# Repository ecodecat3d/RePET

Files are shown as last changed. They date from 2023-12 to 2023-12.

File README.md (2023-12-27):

# RePET

RePET is a groundbreaking system designed for 3D printing using plastic bottles as raw material. The key to this system lies in the combination of various components that collaborate in transforming plastic bottles into filament suitable for 3D printing. Firstly, a heating block capable of reaching 230 degrees Celsius is complemented by a 1.6mm nozzle, playing an essential role in allowing controlled filament output.

The process begins with the preparation of plastic bottles, which are cut into strips using a specialized bottle cutter. These strips are then joined to form a larger coil, ensuring a continuous supply during printing and avoiding interruptions each time a bottle strip is depleted. During the printing process, the coil passes through the heating block, where the application of heat causes the deformation of the strips, generating the required 1.75mm filament.

The final stage of the process involves the entry of the deformed filament into the 3D printer's extruder. At this point, the printer's motor takes on the responsibility of generating the necessary force to extrude the filament in a controlled manner. This approach not only stands out for its technical innovation but also promotes sustainability by reusing materials, contributing to the reduction of plastic waste, and providing a creative and eco-friendly solution for 3D printing manufacturing.

### Atention!
This system has been implemented for Mingda printers. You can use the discount code 'ecodecat3d' for a €50 discount on your printers (Link to their website: https://3dmingdaofficial.com/es/collections/magician-series/products/magician-x2). If you wish to implement the system on your printer, you will need to edit the provided STEP files for your printer. Prior to implementation, ensure that the extruder can generate a minimum torque of 5kg*cm (equivalent to a Nema17 motor), operates at 24V, and is capable of printing at 255 degrees.



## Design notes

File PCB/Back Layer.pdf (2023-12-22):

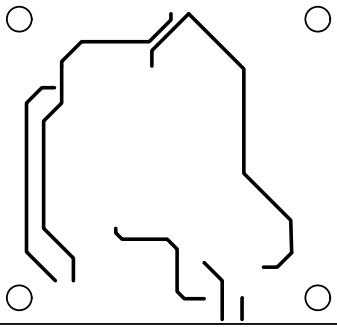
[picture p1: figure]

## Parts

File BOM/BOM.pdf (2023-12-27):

EXTRUDER
COMPONENT | LINK | UNITS
Reductor 24V - 5V | ALIEXPRESS (https://s.click.aliexpress.com/e/_DCE2X0N) | 1
Wemos D1 Mini | ALIEXPRESS (https://s.click.aliexpress.com/e/_DBl6T5X) | 1
10K, 1K resistances | ALIEXPRESS (https://s.click.aliexpress.com/e/_DdqEEZT) | 1
Push Button NO | ALIEXPRESS (https://s.click.aliexpress.com/e/_Dedzl33) | 1
2 pin 2,54mm Male | ALIEXPRESS (https://s.click.aliexpress.com/e/_DkpdfzR) | 1
Heat Shrink | ALIEXPRESS (https://s.click.aliexpress.com/e/_DdkWyCv) | 1
16 AWG Cable | ALIEXPRESS (https://s.click.aliexpress.com/e/_DEuP3uV) | 1
2,4 pin Connector with Cable JST ALIEXPRESS (https://s.click.aliexpress.com/e/_DBptfr3) | 1
2 pin Borna Clema | ALIEXPRESS (https://s.click.aliexpress.com/e/_DDZfU8v) | 2
Display OLED | ALIEXPRESS (https://s.click.aliexpress.com/e/_DC1YlgV) | 1
MOSFET IRF540N | ALIEXPRESS (https://s.click.aliexpress.com/e/_DEaOzYH) | 1
Nozzle | ALIEXPRESS (https://s.click.aliexpress.com/e/_DCAacLP) | 1
24V 40W Resistance | ALIEXPRESS (https://s.click.aliexpress.com/e/_DFfyOQz) | 1
NTC 100k Thermistor | ALIEXPRESS (https://s.click.aliexpress.com/e/_DmHDuTB) | 1
V6 Heating Block + Silicone | ALIEXPRESS (https://s.click.aliexpress.com/e/_DC10nPL) | 1
Metal Bracket | ALIEXPRESS (https://es.aliexpress.com/item/1005005616846654.html?curPageLogUid=VpQ3u38IZQwg) | 1
M2,5x5 mm Srews | ALIEXPRESS (https://es.aliexpress.com/item/10000183209605.html?curPageLogUid=ymxGWMtahMt3) | 4
M3x8 mm Screws | ALIEXPRESS (https://es.aliexpress.com/item/10000183209605.html?curPageLogUid=ymxGWMtahMt3) | 6
M3x12 mm Screws | ALIEXPRESS (https://es.aliexpress.com/item/10000183209605.html?curPageLogUid=ymxGWMtahMt3) | 2
M3 Washers | ALIEXPRESS (https://es.aliexpress.com/item/1005003991819416.html?curPageLogUid=HeumBoNx9dxM) | 4
M3 Nuts | ALIEXPRESS (https://es.aliexpress.com/item/1005005824565515.html?curPageLogUid=5K9Ad8LFkq4m) | 6
PCB (Gerber File) | GITHUB (https://github.com/ecodecat3d/RePET/tree/main/PCB) | 1
Insulating Board (Gerber 2 File) | GITHUB (https://github.com/ecodecat3d/RePET/tree/main/PCB) | 3
PRICE (APROX) | 30 €

BOTTLE CUTTER
COMPONENT | LINK | UNITS
M6x20mm Screw | ALIEXPRESS (https://es.aliexpress.com/item/32968601031.html?curPageLogUid=7SVZ80Q8aYu4) | 1
M6 Nut | ALIEXPRESS (https://es.aliexpress.com/item/1005005221632387.html?curPageLogUid=IwZssWaGQjPI) | 1
TOTAL(APROX) | 3 €

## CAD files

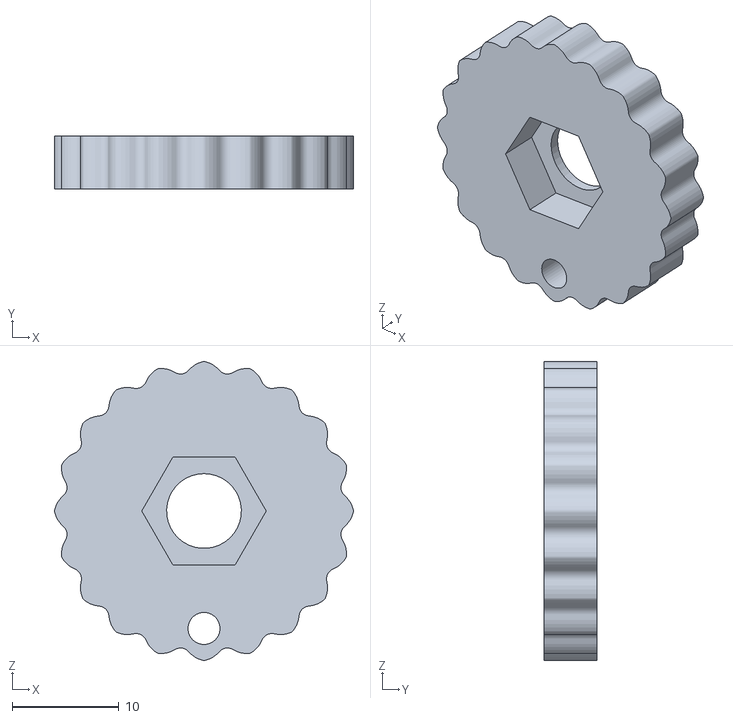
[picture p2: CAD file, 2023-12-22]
Bottle Cutter STLs/Roller.STL
28.0 x 5.00 x 28.0

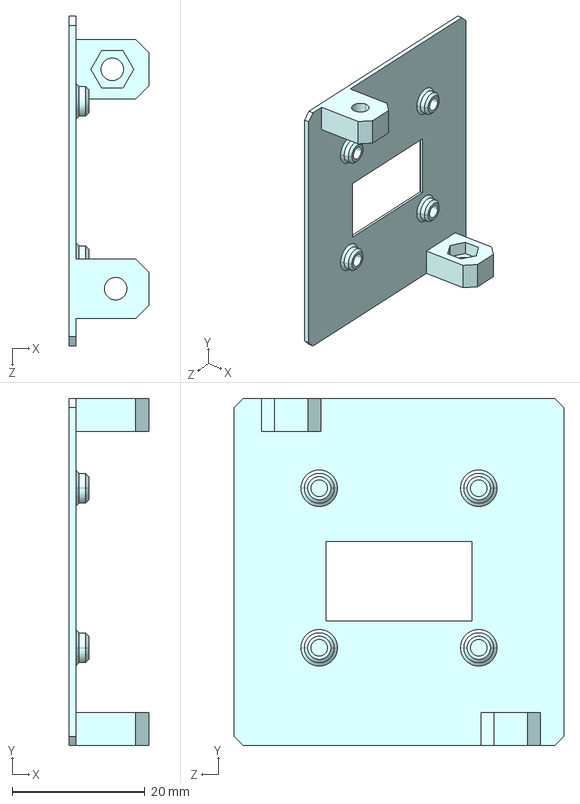
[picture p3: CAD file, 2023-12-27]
Editable Files/Box Lid.STEP
12.0 x 52.2 x 49.6 mm

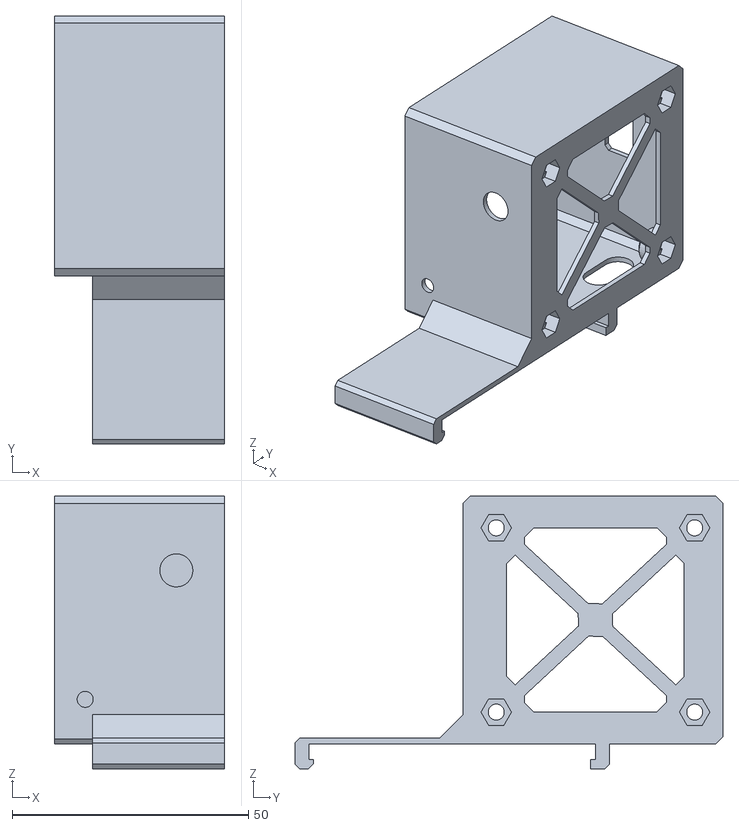
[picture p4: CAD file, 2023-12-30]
Extruder STLs/Box.STL
36.0 x 90.6 x 57.7

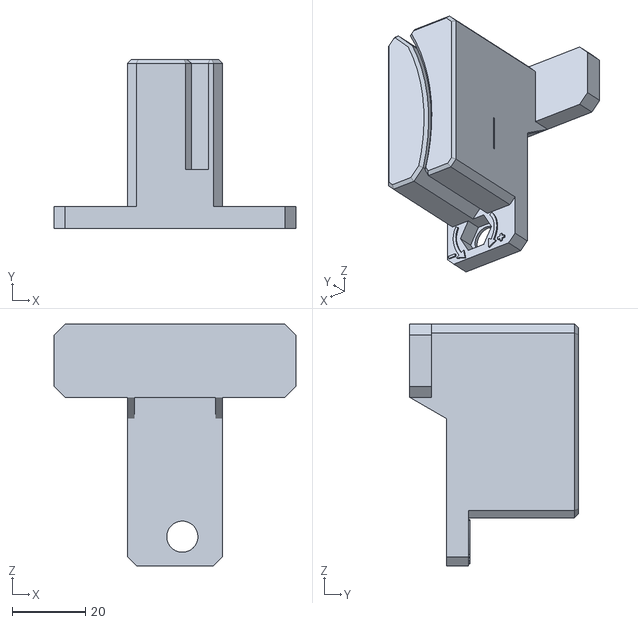
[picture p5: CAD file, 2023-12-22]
Bottle Cutter STLs/Structure.STL
66.0 x 46.0 x 66.0

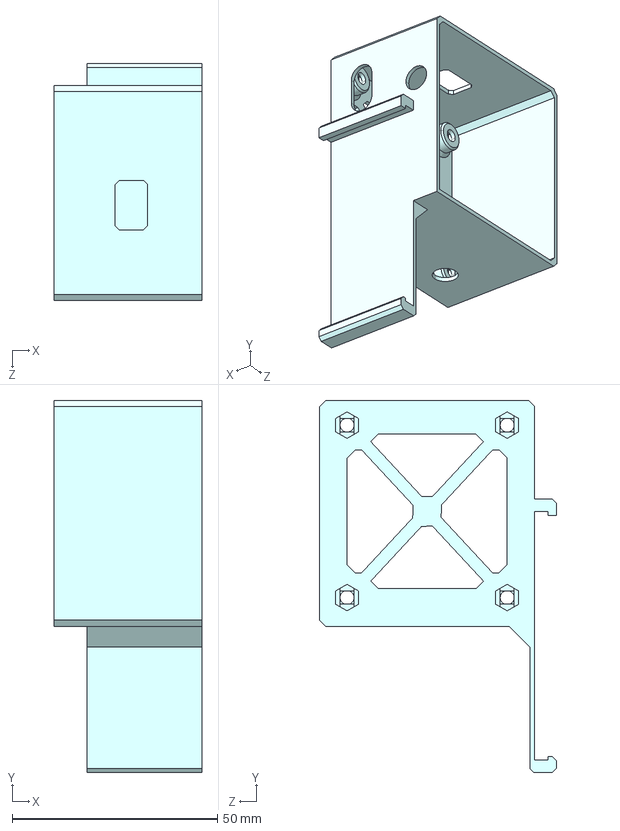
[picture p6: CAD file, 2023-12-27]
Editable Files/Box.STEP
36.0 x 90.6 x 57.7 mm

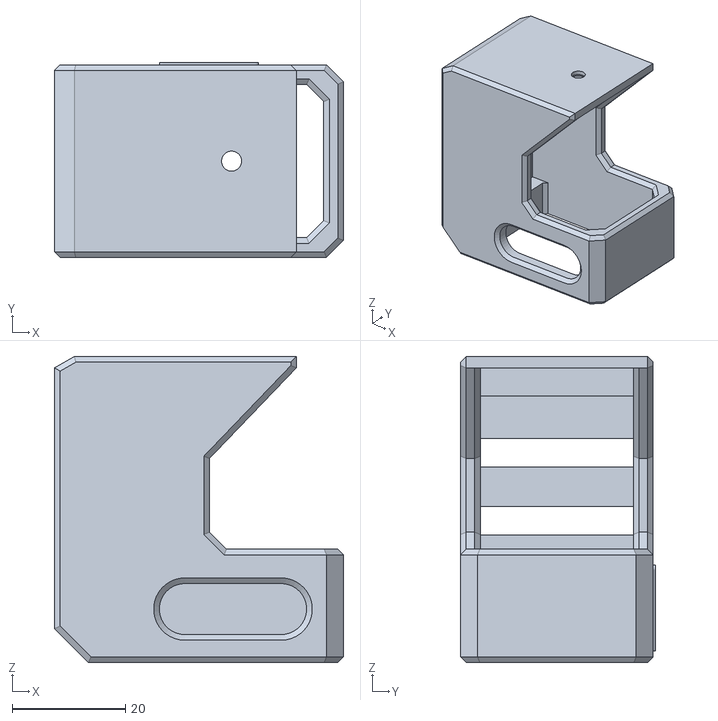
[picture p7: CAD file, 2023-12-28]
Extruder STLs/Extruder.STL
51.0 x 34.4 x 54.0

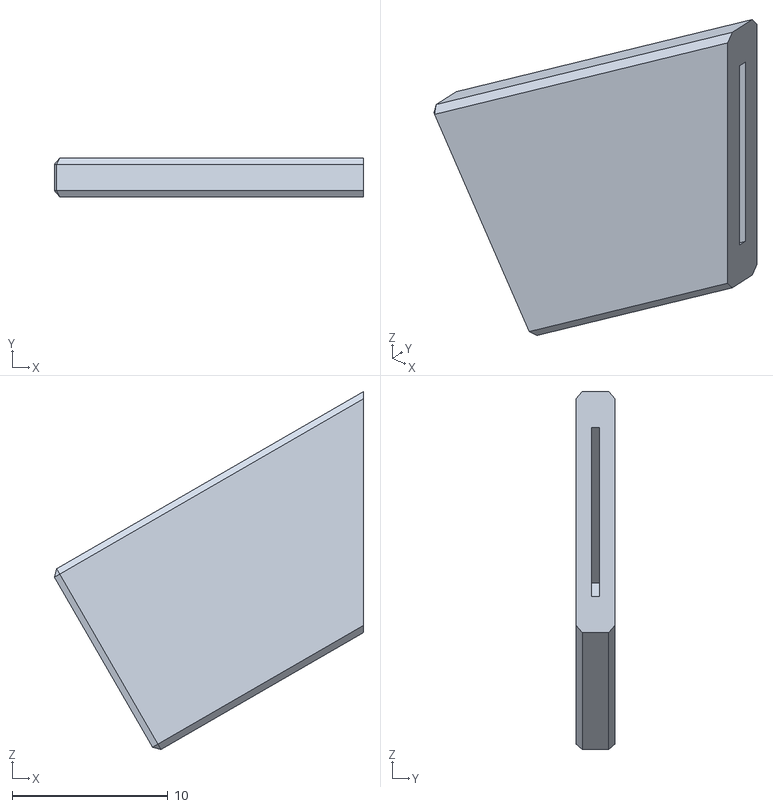
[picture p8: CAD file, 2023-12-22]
Bottle Cutter STLs/Handle.STL
19.9 x 2.50 x 23.0

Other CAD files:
Editable Files/Extruder.STEP
Extruder STLs/Box Lid.STL
Editable Files/Structure.STEP
Editable Files/Handle.STEP
Editable Files/Roller.STEP

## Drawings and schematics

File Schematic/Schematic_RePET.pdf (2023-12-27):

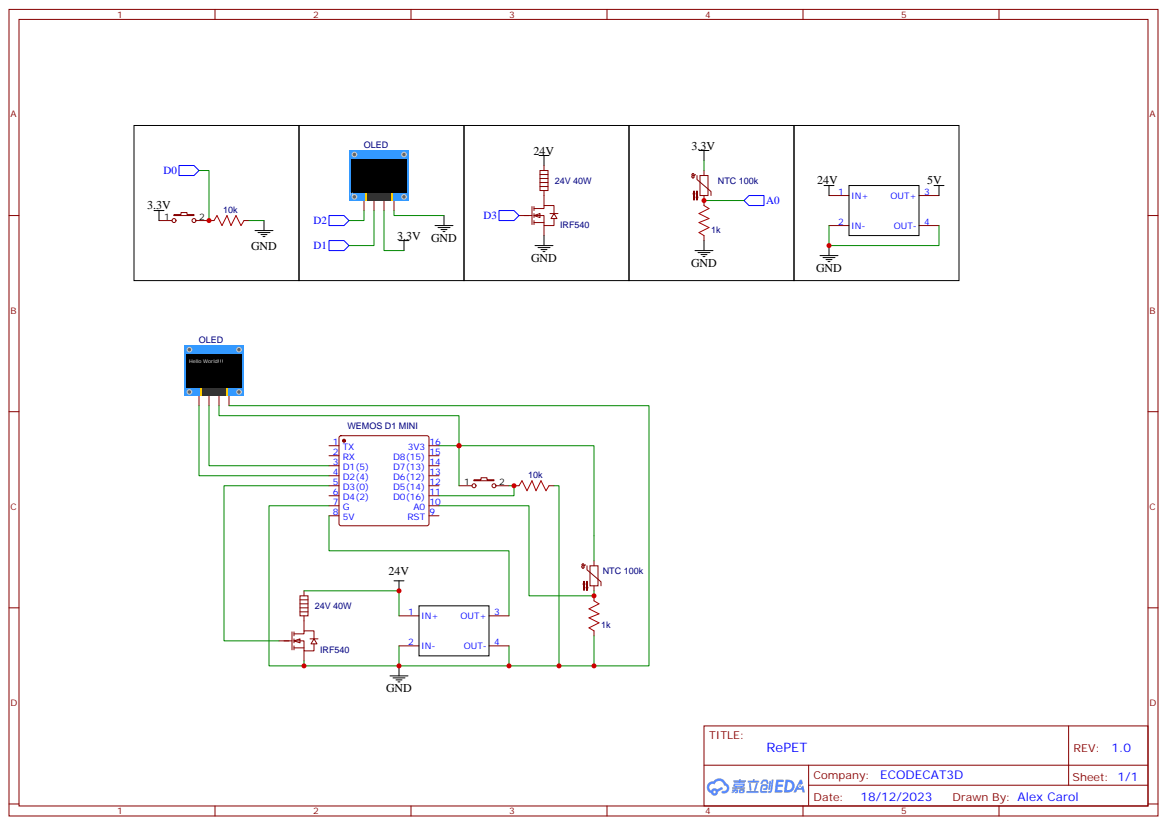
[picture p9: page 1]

Drawn By: Alex Carol

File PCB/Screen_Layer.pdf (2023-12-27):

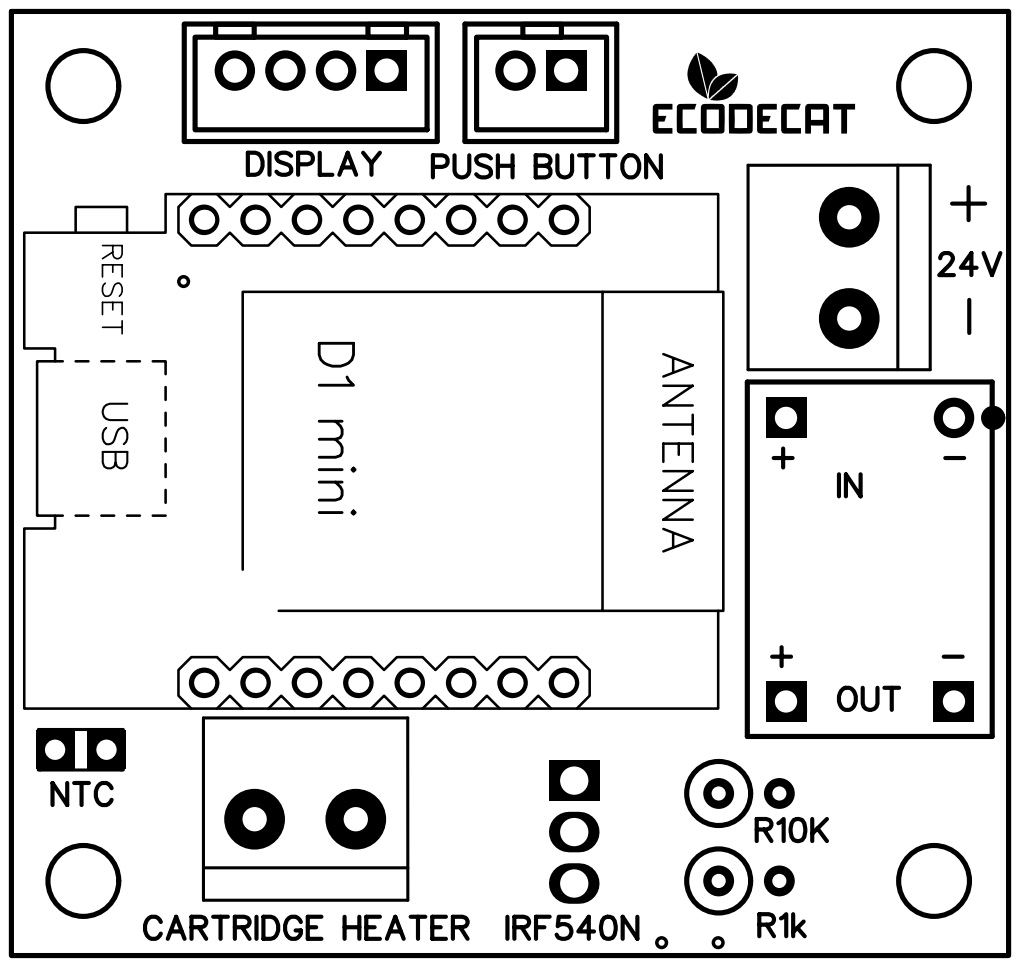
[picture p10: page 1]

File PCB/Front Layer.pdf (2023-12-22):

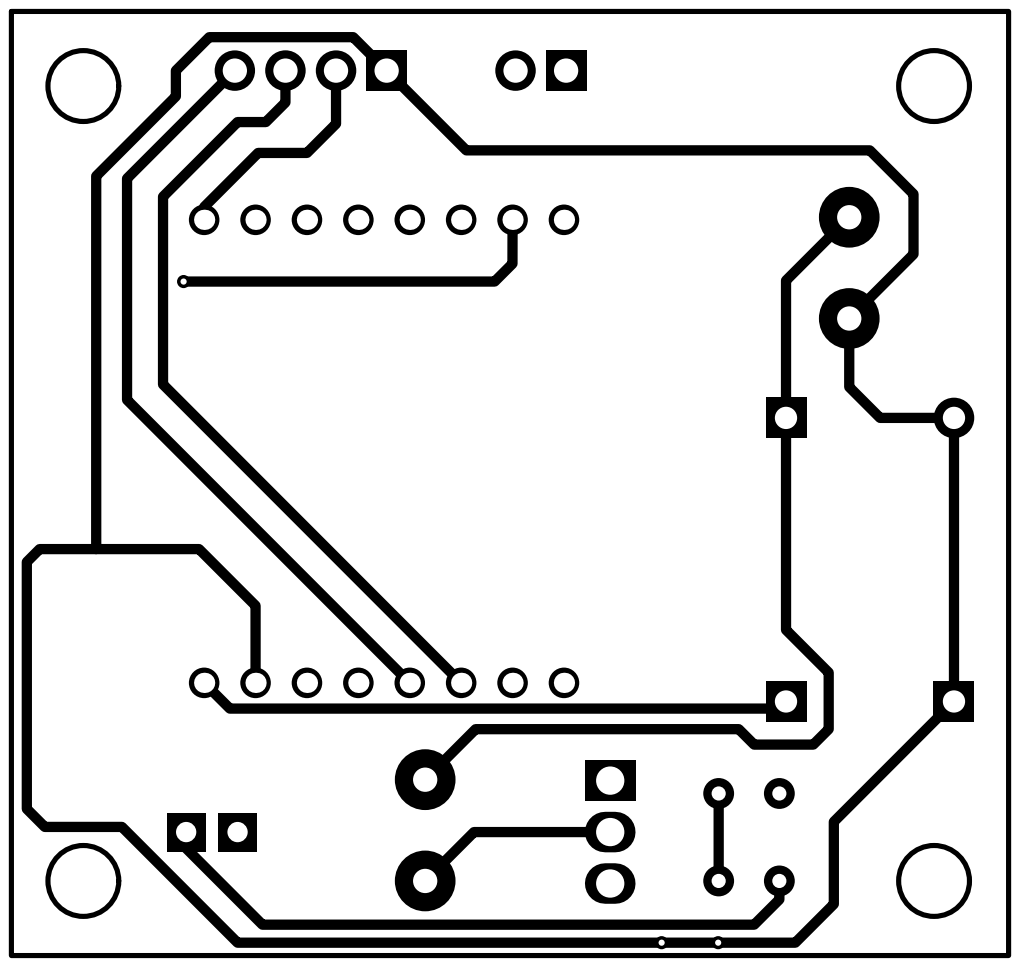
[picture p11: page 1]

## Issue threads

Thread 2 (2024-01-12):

12 volt printer

cocolino83, 2024-01-12:
beautiful project.  I would like to make it happen, but first I would like to ask you two questions.  My printer is 12 volt, so I was wondering if the esp code should be changed and if any electronic components should be changed?  Thank you

ecodecat3d, 2024-01-12:
You will have to use 12V resistance

El dv, 12 gen. 2024 a les 20:33 cocolino83 ***@***.***> va
escriure:

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

cocolino83, 2024-03-23:
HI.  I did the project.  I have a little problem!  I'm not clear on the PIN scheme for the irf540.  I attach you a photo.  I would be grateful if you give me some help.  I already loaded the firewall and everything works.  but I don't know why when I connected the extruder and the temperature sensor my esp burned out.  If you have any tips on this I would be grateful.  A thousand thanks.

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

cocolino83, 2024-04-01:
I finished your project 🫶✌️ these days I will keep it with some material.  👍
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

PaskuRt, 2024-07-19:
hola, estoy intentando construir tu hermoso proyecto y tengo un problema que no se resolver, he construido la electrónica y en mi primera prueba ha empezado a calentar bien pero nunca corto la corriente, no sé si se debe a una mala conexión del MOSFET, creo que este murió, conecte un segundo MOSFET y ahora sí tengo conectado el pin gate del MOSFET el sistema no se enciende, solo cuando desconecto el gate se enciende pero sigue sin control, creo que mi problema está en el cableado del MOSFET, alguien me puede ayudar?

PaskuRt, 2024-07-19:
Hello, I am trying to build your beautiful project and I have a problem that cannot be solved, I have built the electronics and in my first test it started to heat up well but it never cut the power, I don't know if it is due to a bad connection of the MOSFET, I think Since this one died, I connected a second MOSFET and now I do have the gate pin of the MOSFET connected, the system does not turn on, only when I disconnect the gate it turns on but still has no control, I think my problem is in the wiring of the MOSFET, can someone help me? help?

jortec, 2024-07-30:
Hi, I'm also checking this project, I haven't tested it yet because it gives an error when charging the wemos, how did you load the Arduinio, can you help, are you using the correct MOSFET? If you can load the Arduino program, I will send you photos of my connection, best regards

PaskuRt, 2024-07-31:
Hello, first of all, I am using the correct MOSFET, since they are the ones listed in the project. Secondly, I had no problems uploading the program to the Arduino. However, you must have the display and PID libraries installed on your PC.

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

caracolmaker, 2024-08-02:
> Hola, lo primero es que estoy usando el MOSFET correcto, ya que son los que aparecen en el proyecto. En segundo lugar, no tuve problemas para subir el programa al Arduino. Sin embargo, debes tener instaladas las librerías de display y PID en tu PC.
> […](#)
> Sobre 31 jul 2024 a las 1:59, jortec ***@***.***> escribió: Hola, yo también estoy revisando este proyecto, aún no lo he probado porque da error al cargar los wemos, ¿cómo cargaste el Arduino?, ¿me puedes ayudar?, ¿estás usando el MOSFET correcto? Si puedes cargar el programa de Arduino, te enviaré fotos de mi conexión, saludos. Responde a este correo electrónico directamente, míralo en GitHub o anula la suscripción. Recibes esto porque comentaste.ID del mensaje: ***@***.***>
How have you uploaded the program to Arduino.  With Arduino ide it doesn't recognize it.  It's probably something very simple but I can't figure it out.

Como has cargado el programa a Arduino. Con Arduino ide no me lo reconoce. Seguramente sea algo muy sencillo pero no doy con ello.

PaskuRt, 2024-08-02:
Ya te entiendo, cuando descargues el programa, con el ratón y botón derecho dale a editar nombre, escribe .Ino al final y guardas, verás como ya carga

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

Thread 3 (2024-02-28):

Nozzle Size

hkup1130, 2024-02-28:
Hi! Your project is super cool and I’m ordering the parts to make one. I was wondering what size nozzle you use. Do you drill out a nozzle to be 1.6 mm or is there a 1.6 mm nozzle that you purchase?

TrueBluente, 2024-06-01:
I have not built this project but a Petamentor v1 and I just drilled out the nozzle and sanded it(carefully), so there are no sharp edges.

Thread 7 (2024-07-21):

system does not activate the mosfet

PaskuRt, 2024-07-21:
First of all, thank you for sharing your project, I have a problem with activating the mosfet, it does not open and when measuring the voltage between terminal D3 and ground it fluctuates between 0.8v when it should be on and 0v when it is off, I don't know what the reason why this happens and I have already tried several mosfets, I would appreciate if someone could clarify what is happening and what the solution would be, I am quite frustrated, thank you

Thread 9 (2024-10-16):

Arduino quemado

milerato, 2024-10-16:
Buenos dias
He realizado todo el montaje a falta del modulo calefactor, todo parecia funcionar perfectamente, reconocia temperatura y al pulsar el boton cambiaba la imagen indicando que empezaba a calentar.
En la salida al calefactor puse un polimetro para medir y ví que salian 24V, me extrañó, pensaba que no debería tener voltaje la salida, pulsé el botón y la imagen del display cambió indicando que empezaba a calentar, en ese momento el arduino echó a arder, nunca mas volvió a arrancar claro, he pedido otro pero lo que no entiendo es porque se ha quemado y porque salen 24V cuando la salida al calefactor debe estar en reposo.
¿El propio polimetro me generó un retorno?
¿El transistor puede estar jodido?
muchas gracias de antemano, me encanta el proyecto
Saludos

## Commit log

2023-12-22 Create Arduino Program
2023-12-22 Rename Arduino Program to Program/Arduino Program
2023-12-22 Update Arduino Program
2023-12-22 Create BOM
